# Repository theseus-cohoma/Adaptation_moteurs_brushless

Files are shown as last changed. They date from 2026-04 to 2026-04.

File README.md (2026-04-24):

# Adaptation_moteurs_brushless

Objectif du système (boucle de régulation) :



Le but est de piloter un moteur brushless via une carte ESC (Electronic Speed Controler) puis de récupérer la vitesse du moteur via des sondes à effet Hall grâce à un STM32.
Ce STM32 ainsi que l'ESC et le Jetson Nano seront connectés entre eux grâce au protocole de communication CAN.

L'ESC utilisé sera le B-G431B-ESC1 (https://www.st.com/en/evaluation-tools/b-g431b-esc1.html).

Une boite à été designée pour protéger l'ESC d'éventuels court-circuits.



[Partie basse de la boite](Modélisation_3D/box_part_bas.stl)
[Partie haute de la boite](Modélisation_3D/box_part_haut.stl)

Moteurs Brushless utilisés : BDUAV 6384-120KV SPECS (moteurs de skate électrique achetés sur Amazon, no name, très peu d'infos disponibles, pas de datasheet)



Adaptation transmission : 



L'enjeu était de pouvoir rempalacer les MCC par des Brushess. Il a donc fallut adapter la transmission. Pour cela nous avons modélisé deux disques qui venaient se fixer un sur le moteur Brushless et l'autre sur la gearbox. La liaison entre les deux tubes était effectuée par des tiges en métal sur les abords des diques et les deux axes de rotations de diamètres différents sont accouplés en utilisant un coupleur comme celui ci-dessous.



Les gearbox ont été usinés pour acceuillir 4 trous de fixation et les disques d'adaptation ont été imprimés en carbone.

Le système final qui tourne : 

https://github.com/user-attachments/assets/686f73e8-d420-4f12-8da8-5dcabd13b730

Le système une fois remonté dans l'habitacle du robot : 

https://github.com/user-attachments/assets/fa4666f8-0b14-431a-903d-8bc15e6b51ce

Détermination des caractéristiques techniques du moteur : 



Conception d'une carte de distribution de la puissance pour centraliser toute la partie puissance et éviter des brancehment en parallèle "sauvages":

Schématique : 



Routage :



PCB : 



La carte permet d'importer directement de la batterie et des transformateurs les 3 tensions du robot à savoir Vbatt, +12V et +8,4V via les 3 connecteurs XT60 sur la gauche.
Puis elle permet de redistribuer cette énergie via des connecteurs XT60 et des borniers avec le Vbatt sur la partie haute, le 12V au centre et le 8,4V sur le bas et le haut du PCB.
Il y a également de entrées PWM pour les Servos Moteurs.

Software (tuto) :



On lance d’abord motorControl Workbench > Load project là vous mettez le fichier BON_MOTEUR.stwb6. Et ça vous ouvre directement la page(Image ci-dessous).



A gauche vous avez les paramètres que vous pouvez modifier etc. Pour lancer motor Pilot il faut Generate the Project :



Cliquer sur generate ça le genére (si vous voyez des lignes orange pas d’inquiétude). Une fois la génération finit,il vous suffit d’appuyer sur Run STM32CubeMx.
A ce stade normalement, unpage STM32CubeMx se lance appuyer sur Generate the code. Ensuite, appuyer sur ouvrez un fichier c de la barre à gaucheet appuyez sur RUN.
Pendant ce temps vous pouvez lancer motorpilot via motor Control workbench (bouton à coter de
Generate the project).
Remarque, l’application qui se lancera va dépendre de ce que vous avez cocher dans Application
Configuration.



Dans tous les cas, ceci est la page de base:





Vous pouvez aussi tout contrôler en haut à gauche avec GUI. Enfin, si vous choisissez Load UI il faut choisir le fichier MC_FOC_SDK pour avoir l’interface suivante et contrôler le moteur:



Dans l’onglet Control vous pouvez choisir de le contrôler en Torque ou en Speed. Si jamais vous avez un problème de over current, il faut régler le problème ici :



Dans Digital Filter Duration, il faut augmenter le temps ici j’ai mis 282.35 ns.

REMARQUE IMPORTANTE : IL FAUT à CHAQUE FOIS RE-GENERATE the project > Run
STM32CubeMx > Generate the code > Run un fichier C POUR CHAQUE CHANGEMENT QUE
VOUS FAITES DANS LE SOFTWARE MC WORKBENCH. (En tout cas c’est la seule façon avec
laquelle on arrivait à faire en sorte que les changements dans le software soit pris en compte si
jamais vous trouvez une autre méthode plus court, bien joué).

J’ai fournit les fichier JSON obtenu via MOTOR Profiler. Libre à vous de tester et d’observer les
mesures. Ce software permet d’identifier les « composants » et leurs valeurs du moteur et faute de
datasheet sur les moteurs commandées, on a du faire avec les moyens du bord.

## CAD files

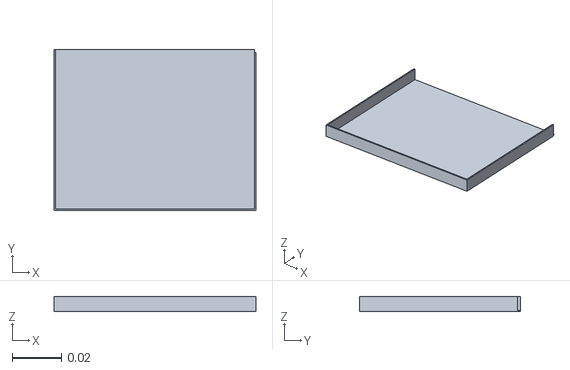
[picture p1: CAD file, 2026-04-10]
Modélisation_3D/cache_poussière_gearbox.stl
0.0824 x 0.0658 x 0.006

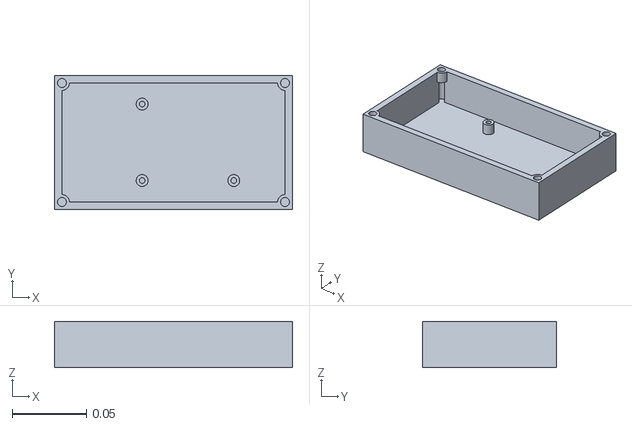
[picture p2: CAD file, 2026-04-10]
Modélisation_3D/box_part_bas.stl
0.16 x 0.09 x 0.031

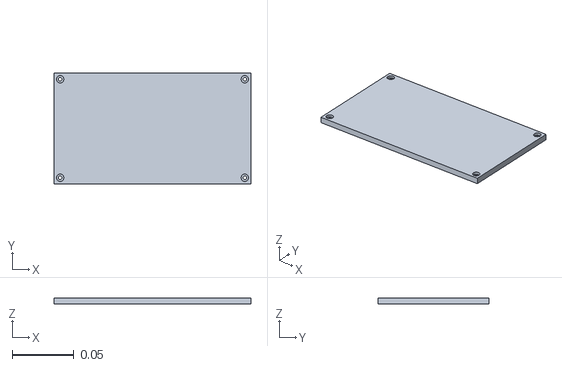
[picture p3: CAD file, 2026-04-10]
Modélisation_3D/box_part_haut.stl
0.16 x 0.09 x 0.005

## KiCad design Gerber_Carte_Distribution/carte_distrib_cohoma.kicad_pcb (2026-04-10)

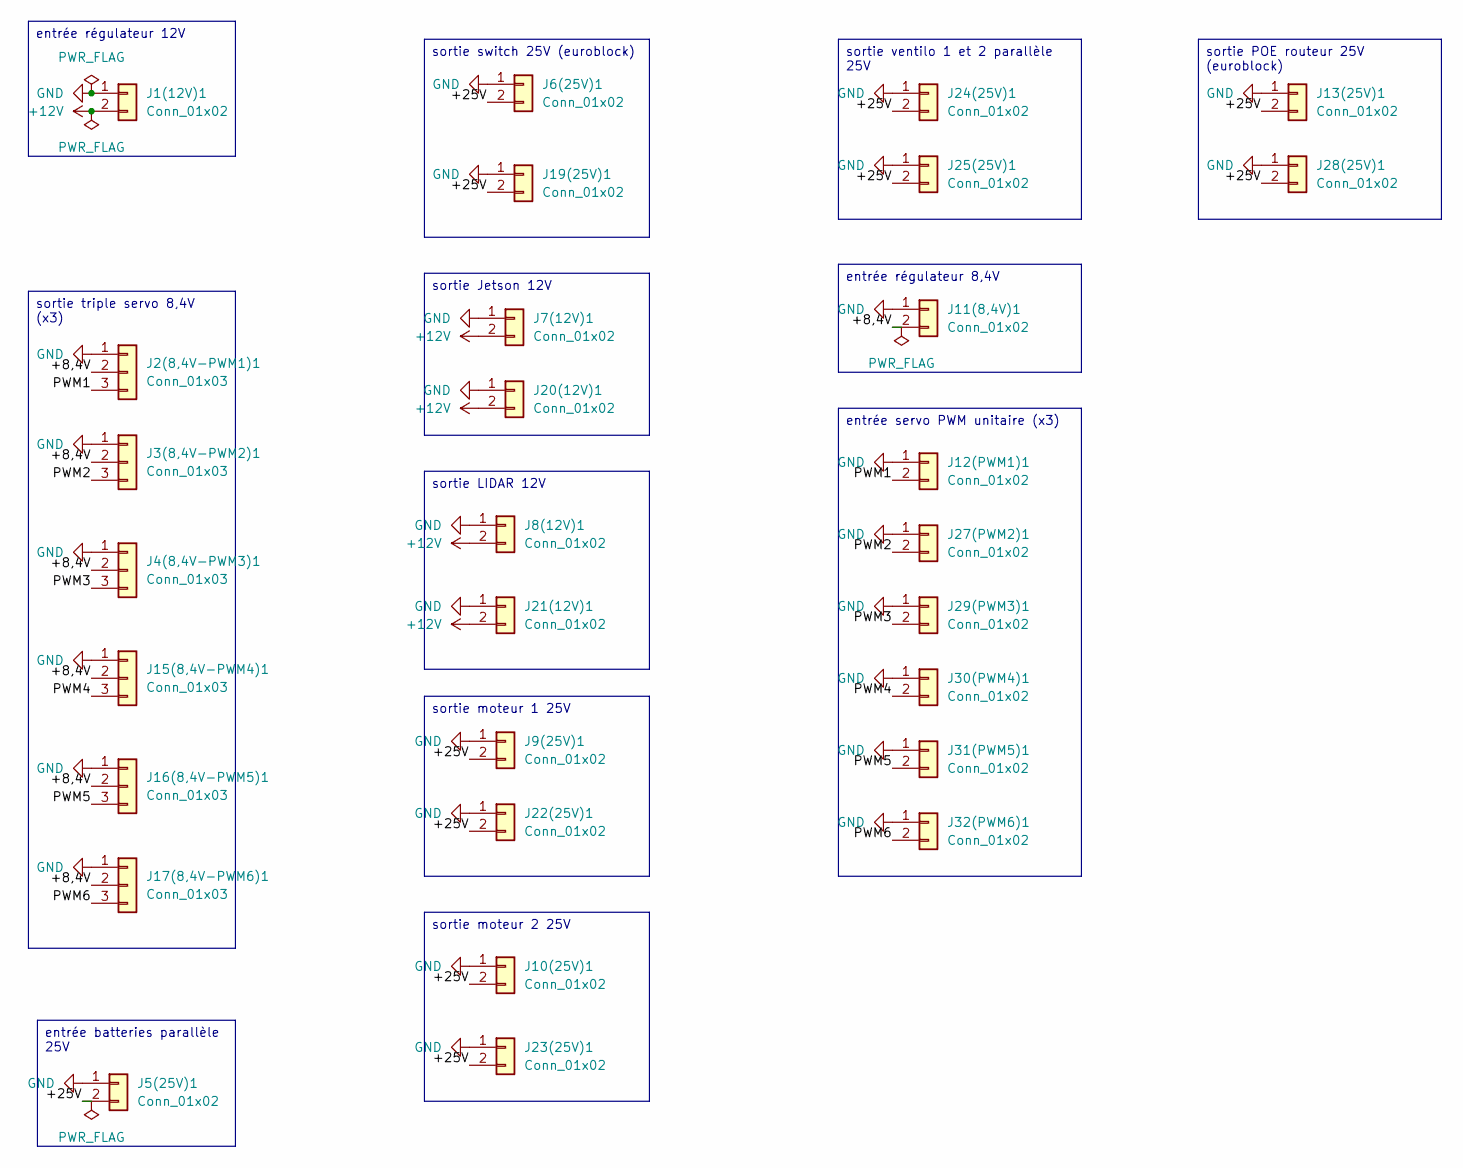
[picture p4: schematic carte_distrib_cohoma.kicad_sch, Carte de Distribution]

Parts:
J1(12V)1, J5(25V)1, J11(8,4V)1: Conn_01x02; AMASS_XT60-M_1x02_P7.20mm_Vertical
J2(8,4V-PWM1)1, J3(8,4V-PWM2)1, J4(8,4V-PWM3)1, J15(8,4V-PWM4)1, J16(8,4V-PWM5)1, J17(8,4V-PWM6)1: Conn_01x03; CONN3_KF301-3P - BLACK_CKE
J6(25V)1, J8(12V)1, J20(12V)1, J22(25V)1, J23(25V)1, J25(25V)1, J28(25V)1: Conn_01x02; HANDSON_KF301-2P
J7(12V)1, J9(25V)1, J10(25V)1, J13(25V)1, J19(25V)1, J21(12V)1, J24(25V)1: Conn_01x02; AMASS_XT60-F_1x02_P7.20mm_Vertical
J12(PWM1)1, J27(PWM2)1, J29(PWM3)1, J30(PWM4)1, J31(PWM5)1, J32(PWM6)1: Conn_01x02; JST_PH_B2B-PH-K_1x02_P2.00mm_Vertical

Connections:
+12V: J1(12V)1.2, J7(12V)1.2, J8(12V)1.2, J20(12V)1.2, J21(12V)1.2
/+8,4V: J2(8,4V-PWM1)1.2, J3(8,4V-PWM2)1.2, J4(8,4V-PWM3)1.2, J11(8,4V)1.2, J15(8,4V-PWM4)1.2, J16(8,4V-PWM5)1.2, J17(8,4V-PWM6)1.2
/+25V: J5(25V)1.2, J6(25V)1.2, J9(25V)1.2, J10(25V)1.2, J13(25V)1.2, J19(25V)1.2, J22(25V)1.2, J23(25V)1.2, J24(25V)1.2, J25(25V)1.2, J28(25V)1.2
/PWM1: J2(8,4V-PWM1)1.3, J12(PWM1)1.2
/PWM2: J3(8,4V-PWM2)1.3, J27(PWM2)1.2
/PWM3: J4(8,4V-PWM3)1.3, J29(PWM3)1.2
/PWM4: J15(8,4V-PWM4)1.3, J30(PWM4)1.2
/PWM5: J16(8,4V-PWM5)1.3, J31(PWM5)1.2
/PWM6: J17(8,4V-PWM6)1.3, J32(PWM6)1.2
GND: J1(12V)1.1, J2(8,4V-PWM1)1.1, J3(8,4V-PWM2)1.1, J4(8,4V-PWM3)1.1, J5(25V)1.1, J6(25V)1.1, J7(12V)1.1, J8(12V)1.1, J9(25V)1.1, J10(25V)1.1, J11(8,4V)1.1, J12(PWM1)1.1, J13(25V)1.1, J15(8,4V-PWM4)1.1, J16(8,4V-PWM5)1.1, J17(8,4V-PWM6)1.1, J19(25V)1.1, J20(12V)1.1, J21(12V)1.1, J22(25V)1.1, J23(25V)1.1, J24(25V)1.1, J25(25V)1.1, J27(PWM2)1.1, J28(25V)1.1, J29(PWM3)1.1, J30(PWM4)1.1, J31(PWM5)1.1, J32(PWM6)1.1

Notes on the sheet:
entrée batteries parallèle 25V
sortie moteur 1 25V
sortie moteur 2 25V
sortie ventilo 1 et 2 parallèle 25V
sortie POE routeur 25V (euroblock)
sortie Jetson 12V
sortie switch 25V (euroblock)
sortie triple servo 8,4V (x3)
sortie LIDAR 12V
entrée régulateur 12V
entrée régulateur 8,4V
entrée servo PWM unitaire (x3)

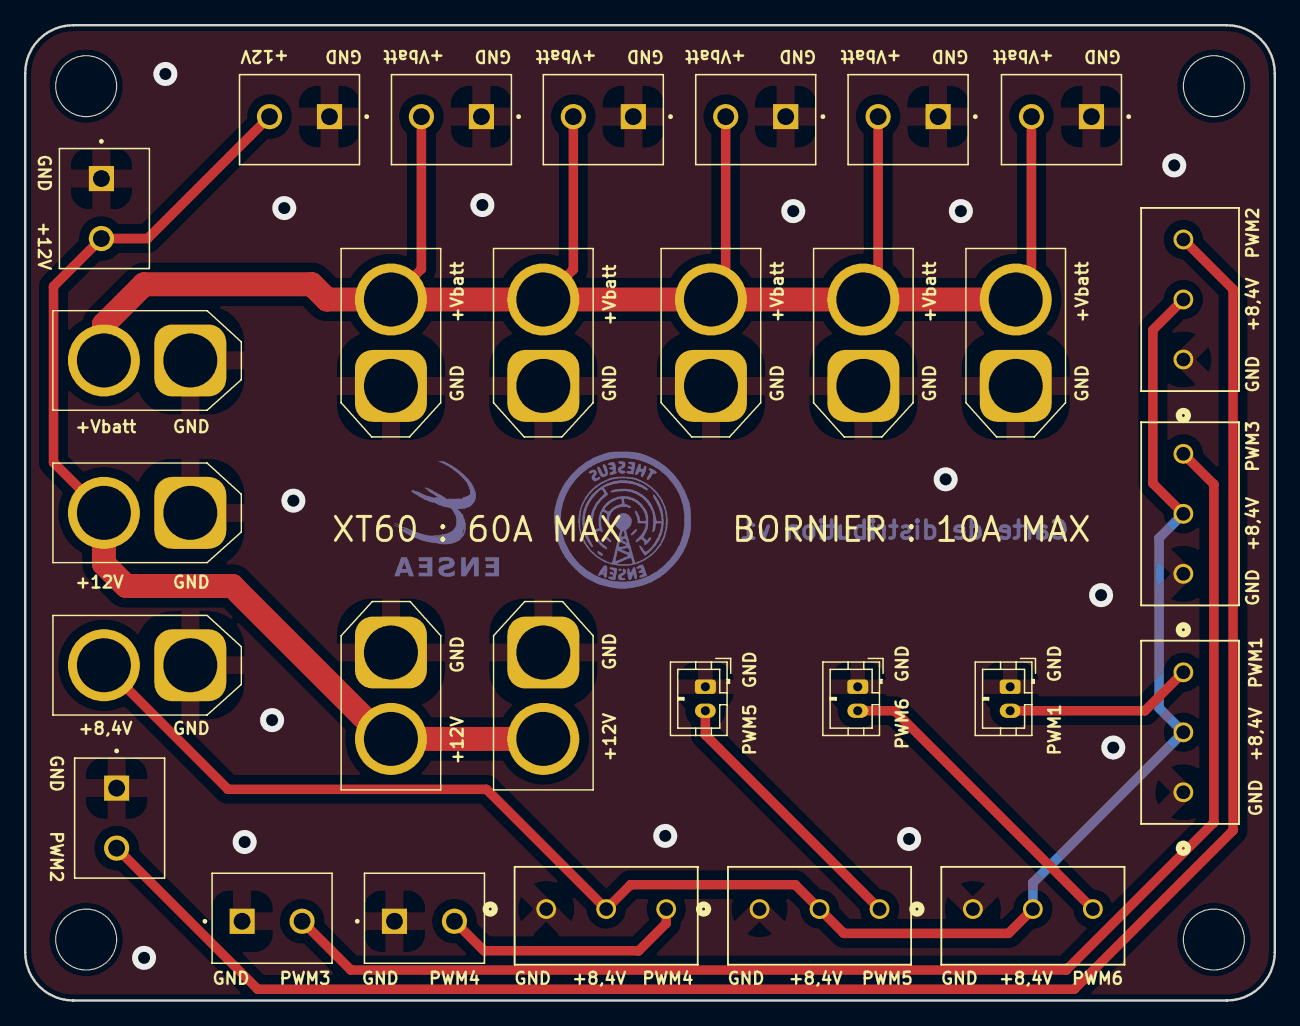
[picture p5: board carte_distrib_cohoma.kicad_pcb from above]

Board: 2 copper layers, 104.1 x 81.3 mm, 29 parts (0 on the bottom side), 10 nets.

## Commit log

2026-04-10 Rename box - Part haut.stl to box_part_haut.stl
    [box_part_haut.stl]
2026-04-10 Rename box - Part bas.stl to box_part_bas.stl
    [box_part_bas.stl]
